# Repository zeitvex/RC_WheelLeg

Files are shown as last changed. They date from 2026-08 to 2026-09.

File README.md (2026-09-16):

关键词：ROBOCON、四足、四轮足、仿生足式、强化学习、RL、Mjlab、Mujoco、Odin1、sim2sim、sim2real。

山东华宇工学院 HYNova 战队轮足机器人项目的开源仓库。

我们是一支从零起步的新队伍。从社团初创到战队成立，从学校历史上首次电赛国一，到 RC 国一，一路走来积累了机械、硬件、控制、仿真和强化学习方面的实践经验。当前仓库已完整开源本项目的机械、硬件、固件、软件、BOM、装配资料、部署文档、训练与比赛版本代码及各类注意事项，希望为起步较晚、正在准备 Robocon 的队伍提供参考。

## 致谢

感谢Robocon青年顾问组对本战队的帮助与支持，感谢[Lain 佬](https://github.com/Lain-Ego0) 的 [LocoWiki](https://github.com/LocoWiki/LocoWiki) 项目对早期方案的参考与启发，衷心感谢哈尔滨工业大学、华南理工大学、东莞理工学院、潍坊科技学院、山东科技大学、太原工业学院、晋中信息学院等院校的战队，在备赛及比赛期间给予我们的鼎力支持与热心帮助。
最后，特别感谢留形科技为 2026 赛季提供的独家赞助与技术支持。

## 战队与项目

* 参赛项目：仿生足式障碍赛
* 最终成绩：全国一等奖，第 7 名，前 5%
* 主要平台：16DOF 串联轮足机器人
* 当前仓库版本：16DOF 串联轮足实机（升级16DOF）

## 版本状态

* 阶段：16DOF 比赛最终版
* 平台：Jetson Orin Nano 8G
* 构型：4 条轮腿，每条腿 3 个腿部关节和 1 个驱动轮
* 执行器：共 16 个执行器（RS02）
* 控制路线：强化学习训练、MuJoCo 仿真、Sim2Sim 验证、Py 与 ROS 2/C++ 双线真机部署
* 当前状态：项目资料已完整开源，包含机械、硬件、固件、软件、BOM、装配、训练、部署和比赛最终版本代码
* 当前版本：`v1.1.1` 最终整理版，补齐完整开源资料说明与代码文档；
* 本仓库为最终完整开源整理版本，后续仅进行必要的问题修正和说明勘误

## 开源内容

本项目沿着“8DOF 基础版本 -> 16DOF 升级版本”的技术路线持续迭代，公开内容也按版本阶段逐步整理和发布。

### 8DOF 基础版本

8DOF 是中期时的串联机器人版本，主要围绕机械结构设计、电机控制、CAN 通信、腿部逆解、PID 调试和基础步态控制展开，为后续的机械升级、仿真训练和真机部署积累了基础经验。完整的 8DOF 机械、硬件和软件资料请查看 [8dof 分支](https://github.com/zeitvex/RC_WheelLeg/tree/8dof)。

### 16DOF 当前版本

当前 `main` 分支主要维护 16DOF 版本的机械、仿真、控制和真机部署资料。

* SolidWorks 2026 版本机械源文件，整机入口为 `02_mechanical/CAD/solidworks/WEEKDOG.SLDASM`。
* 整机、身体、关节、腿部和轮组 STEP 文件，整机入口为 `02_mechanical/STEP/WEEKDOG.STEP`。
* 新一代 `mjlab` 训练任务和本地依赖，位于 `05_software/train/rc_mjlab/`。
* 16DOF 轮足 MuJoCo/MJCF 模型、网格、Sim2Sim 验证工具和早期策略权重。
* 后期 Sim2Sim 工具、导航地图与打点工具、路线数据和抽样 PCD，位于 `05_software/train/rc_mjlab/`。
* IK 轨迹与早期真机控制探索，位于 `05_software/real/ik_real/`。
* 新一代 Python Sim2Real 部署栈，包含策略运行时、电机映射、IMU 接入、站立初始化、安全检查、Web 调试和标定工具。
* Python Sim2Real v2 部署栈，补充电机反馈新鲜度、Odin odom 诊断、命令平滑、Web 运行时诊断和安全监控工具，位于 `05_software/real/sim2real_v2/`。
* ROS 2/C++ Sim2Real 初版工程，将策略热路径迁移到 50 Hz C++ 推理和 200 Hz CAN 电机循环，并加入 ROS 2 消息、命令仲裁、Nav2 和统一启动结构，位于 `05_software/real/sim2real_ros2/`。`sim2real_ros2_v2` 补充导航原型、路线配置、打点工具、遥控串口和 Web/UDP 调试链路，`sim2real_ros2_v3` 整理最终比赛部署、Odin 驱动、TensorRT/ONNX 推理和里程计联调代码，位于 `05_software/real/sim2real_ros2_v2/` 与 `05_software/real/sim2real_ros2_v3/`。
* 新一代 Sim2Real 真机验证视频与预览图。

### 后续整理内容

* 16DOF RL 四轮足相关注意事项以及各类文档。
  
> 当前仓库已完成完整开源整理。请以各目录说明和 Git Tag 对应的版本为准。

## 交流与支持

欢迎正在备赛或对轮足机器人感兴趣的同学加入交流：

* 轮足开源交流群：[点击加入 QQ 群](https://qm.qq.com/q/HkdRYwtAYg)
* 群号：`767195310`

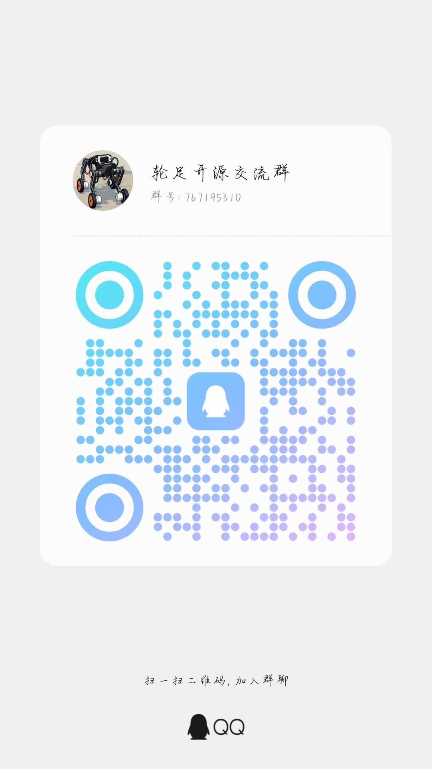
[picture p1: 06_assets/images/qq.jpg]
轮足开源交流群二维码


同时欢迎在群内交流机械设计、硬件搭建、下位机控制、仿真训练、强化学习和真机部署相关问题，也欢迎对本项目提出建议。

## 成员

|成员|方向|主要职责|联系方式|
|-|-|-|-|
|晨小荼(chentu12)|队长 / 算法|构建初创平台；前期负责 8DOF 平台构建与算法，参与硬件和算法方案讨论；后期负责 16DOF 轮足机器人 Odin1 平台建设与硬件实现，负责企业及组委对接，持续推进项目落地。|WX: `r15288746596`<br>QQ: `2898468947`|
|[时维](https://github.com/zeitvex)|技术负责人 / 项管|主导中后期 16DOF 轮足机器人的软件与控制架构，参与机械与硬件方案确定；负责强化学习训练、仿真验证、真机部署、导航集成及项目进度推进和体系建设。|WX: `zeitvex`<br>QQ: `3156045992`|
|[Dichen](https://github.com/Dichen33)|电控 / 算法|负责电控与算法软件架构设计及系统集成。前期完成 8DOF 电机控制、CAN 通信、PID、腿部逆解与步态调试；中后期面向 16DOF 平台负责电机控制、传感器接入、状态估计和导航链路开发，辅助 Odin 接入，并参与仿真验证、强化学习训练及真机部署。|WX: `Dichenccc`<br>QQ: `3357573813`|
|[Sulcunfu](https://github.com/wusi321)|电控 / 机械|参与前期 8DOF 及中后期 8DOF 到 16DOF 的机械升级设计；负责模型总装配、URDF 导出、仿真和算法验证，参与强化学习模型训练优化，配置 Linux 基础部署环境，对接 Odin1 视觉感知、里程计和 IMU 数据，并负责环境建图及导出。|WX: `LcfNotFound`<br>QQ: `3299459360`|
|[王书琪](https://github.com/Beni-537)|机械 / 硬件|负责整机机械结构设计与电气硬件系统搭建；负责 8DOF 开源机械结构的硬件适配，以及 16DOF 架构整体机械结构的建模、优化和 CNC 供应链对接；负责电源管理 PCB 设计与 CAN 总线通信拓扑，为算法和仿真部署提供高刚度、高稳定性的硬件基础。|WX: `DouSfJade`<br>QQ: `3070940094`|

## 实机展示

当前仓库包含 Sim2Real 真机测试记录与比赛初版成果展示，视频与预览图位于 `06_assets/`：

### 最初轮足真机测试记录

<a href="06_assets/videos/early_sim2real.mp4">
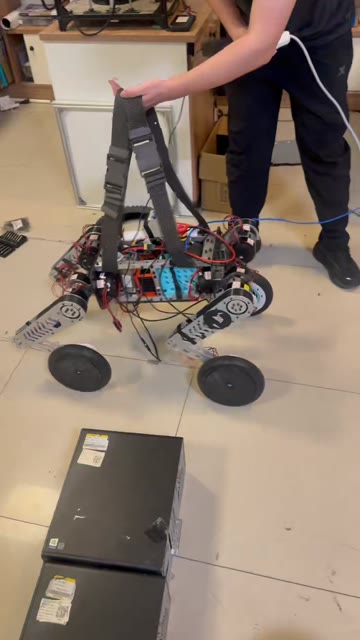
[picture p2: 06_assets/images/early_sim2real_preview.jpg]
第一代 Sim2Real 真机测试记录
  
</a>

第一代 Sim2Real 真机测试记录，时长约 41 秒。点击预览图播放或下载原视频。

### 最终比赛测试记录

<a href="06_assets/videos/sim2real.mp4">
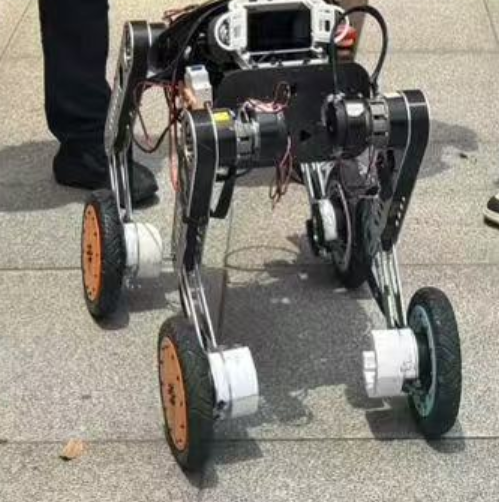
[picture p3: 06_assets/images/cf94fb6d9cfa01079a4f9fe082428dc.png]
比赛初版成果
  
</a>

该视频为完赛效果演示视频，画质为 1280×720 横屏，总时长约 1 分 20 秒，与比赛实际时长接近。点击预览图可播放或下载原视频。

## 目录结构

```text
RC_WheelLeg/
├─ 01_doc/          # 项目技术文档和使用说明
├─ 02_mechanical/   # SolidWorks CAD、STEP 和机械源资料
├─ 03_hardware/     # 自研电路、接线、BOM、传感器与计算平台说明
├─ 04_firmware/     # MCU 或其他嵌入式控制器固件
├─ 05_software/     # 强化学习训练、MuJoCo、Sim2Sim、Sim2Real 和工具
├─ 06_assets/       # 图片、视频和测试结果
├─ .gitignore
└─ README.md
```

## 工程入口

机械资料：

* [`02_mechanical/README.md`](02_mechanical/README.md)
* [`02_mechanical/CAD/solidworks/WEEKDOG.SLDASM`](02_mechanical/CAD/solidworks/WEEKDOG.SLDASM)
* [`02_mechanical/STEP/WEEKDOG.STEP`](02_mechanical/STEP/WEEKDOG.STEP)

软件资料：

* [`05_software/README.md`](05_software/README.md)
* [`05_software/train/README.md`](05_software/train/README.md)
* [`05_software/train/rc_mjlab/README.md`](05_software/train/rc_mjlab/README.md)
* [`05_software/train/rc_mjlab/sim2sim/README.md`](05_software/train/rc_mjlab/sim2sim/README.md)
* [`05_software/train/rc_mjlab/tools/nav_tools/README.md`](05_software/train/rc_mjlab/tools/nav_tools/README.md)
* [`05_software/real/README.md`](05_software/real/README.md)
* [`05_software/real/sim2real/README.md`](05_software/real/sim2real/README.md)
* [`05_software/real/sim2real_v2/README.md`](05_software/real/sim2real_v2/README.md)
* [`05_software/real/sim2real_ros2/README.md`](05_software/real/sim2real_ros2/README.md)
* [`05_software/real/sim2real_ros2_v2/README.md`](05_software/real/sim2real_ros2_v2/README.md)
* [`05_software/real/sim2real_ros2_v3/README.md`](05_software/real/sim2real_ros2_v3/README.md)

媒体资料：

* [`06_assets/README.md`](06_assets/README.md)
* [`06_assets/images/cf94fb6d9cfa01079a4f9fe082428dc.png`](06_assets/images/cf94fb6d9cfa01079a4f9fe082428dc.png)
* [`06_assets/videos/early_sim2real.mp4`](06_assets/videos/early_sim2real.mp4)
* [`06_assets/videos/sim2real.mp4`](06_assets/videos/sim2real.mp4)

## 软件相关

当前 `05_software/` 保存完整软件相关资料：

```text
MJCF + mjlab task
        |
        v
   PPO 训练策略
        |
        +----> MuJoCo 独立模型调试
        |
        +----> Sim2Sim 策略验证
        |
        +----> Python Sim2Real / v2 ----> 电机 / IMU
        |
        +----> ROS 2/C++ Sim2Real / v2 / v3 -> CAN / IMU / 导航与比赛部署

IK real --------------------------------> 电机
```

其中 `rc_mjlab` 是自包含训练与仿真工程，包含 `src/robot` 训练任务、`mjcf` 模型、`mujoco_sim` 独立调试工具、`sim2sim` 验证工具、本地 `mjlab` 依赖和早期策略权重。

`sim2real` 当前部署 `53D -> 16D` 策略模型，控制频率为 50Hz，包含站立初始化、站立平衡、运行时安全检查、零命令保持和首次命令平滑释放逻辑。部署前应先阅读 `05_software/real/sim2real/README.md`、`DEPLOYMENT.md` 和 `ORIN_NANO_DEPLOYMENT.md`。

`sim2real_v2` 对应 Python Sim2Real v2，保留 `53D -> 16D` 策略接口，并增加电机反馈新鲜度、Odin odom 诊断、命令平滑、Web 运行时诊断和安全监控工具。部署前应先阅读 `05_software/real/sim2real_v2/README.md` 和 `DEPLOYMENT.md`。

`sim2real_ros2` 是 ROS 2/C++ Sim2Real 初版；`sim2real_ros2_v2` 补充导航原型、路线配置、打点工具、遥控串口和 Web/UDP 调试链路；`sim2real_ros2_v3` 整理最终比赛部署、Odin 驱动、TensorRT/ONNX 推理和里程计联调。完整入口见 `05_software/real/sim2real_ros2/README.md`、`05_software/real/sim2real_ros2_v2/README.md` 与 `05_software/real/sim2real_ros2_v3/README.md`。

## 安全说明

* 首次运行前必须架空机器人，并确认电机 ID、方向、零位、限位和关节映射。
* 调试时必须确保遥控器、上位机或部署脚本中的急停链路可用。
* 不应在未核对机械限位、仿真模型、策略输出尺度和电机映射的情况下直接上电运行。
* 强化学习策略和 Sim2Real 部署需要先完成离线检查、仿真验证、低速空载测试和小幅动作测试。
* 本项目可能产生较大关节力矩，使用者需要自行承担硬件调试风险。
* 零位设置需在机器人稳定支撑状态下完成，并记录机身、足端、膝关节和轮组的实际姿态，避免后续模型与真机坐标不一致。

## 许可证

本项目采用 [MIT License](LICENSE) 授权。

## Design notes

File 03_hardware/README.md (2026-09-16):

# 硬件

本目录用于保存 16DOF 轮足机器人的自研电路、接线图、BOM、传感器与计算平台说明。

第三方硬件资料不作为自研成果提交。

当前目录仅有范围说明，尚未归档 16DOF 平台的自研原理图、PCB、BOM 或正式接线图，不应将本目录视为已完成的硬件开源包。

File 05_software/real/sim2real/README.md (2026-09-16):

# `sim2real`

本目录是第一代 Python Sim2Real 快照，对应 `v0.3.0`。下文“当前”均指该历史快照，不指仓库 `main` 的最终 ROS 2 v3。

该快照只部署当时的 `53D -> 16D` Rough 模型，不兼容更早的 Crawl、多策略和其他历史观测契约。

## 当前部署模型

- 使用文件：`policies/model_rough.pt`
- 原始说明记录的来源名：`model_2000.pt`；该同名源文件未随本目录归档，仓库只保留重命名后的 `policies/model_rough.pt`

## 当前 actor 输入

- 单帧 `53D`
- 顺序：
  - `base_ang_vel * 0.25`
  - `projected_gravity`
  - `command`
  - `joint_pos_rel`（12）
  - `joint_vel_rel * 0.05`（12）
  - `wheel_vel * 0.05`（4）
  - `last_actions`（16）

不包含：

- `base_lin_vel`
- `height_scan`

## 当前控制参数

- 控制频率：`50Hz`
- 站立保持：`startup/stand_balance.py`
- `hip_abduction` 缩放：`0.125`
- 其他腿关节缩放：`0.25`
- 轮速缩放：`5.0`
- 腿 LPF：`5Hz`
- 轮 LPF：`15Hz`
- 零命令抑制：默认开启，可通过 `config.yaml > policy.enable_zero_cmd_suppression` 关闭
- 零命令保持：默认开启，可通过 `config.yaml > policy.hold_zero_command_pose` 控制
- 首次命令解锁：默认开启，可通过 `config.yaml > policy.require_active_command_to_release` 控制

## 当前站立逻辑

- `startup`：从实测姿态过渡到默认站姿
- `stand_balance`：根据 `IMU roll/pitch + gyro` 动态修正四条腿目标
- `runtime`：只有站立稳定后才进入策略控制

这次改动的重点是：策略不再承担“先把身体撑住”的职责。

另外当前部署逻辑改成：

- 零命令时默认不让策略直接接管腿和轮，保持站立目标
- 命令从零变为非零时，策略输出在 `command_release_s` 内平滑放开

## 启动命令

默认前提：当前目录是 `05_software/real/sim2real/`

纯 `python`：

```bash
python -m pip install -r requirements-orin.txt
python tools/alignment_check.py --policy policies/model_rough.pt --manifest deployment_manifest.yaml
python tools/standalone_check.py
python main.py --dry-run
python main.py
python web/server.py --host 0.0.0.0 --port 8080
```

Windows 本机可使用目标虚拟环境中的 Python；不要依赖个人机器的绝对安装路径：

```bash
python -m pip install -r requirements-orin.txt
python tools\alignment_check.py --policy policies\model_rough.pt --manifest deployment_manifest.yaml
python tools\standalone_check.py
python main.py
python web\server.py --host 0.0.0.0 --port 8080
```

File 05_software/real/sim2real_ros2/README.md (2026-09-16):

# ROS 2/C++ Sim2Real 初版

本目录归档 `real/sim2real_ros2`，对应 `v0.10.0`。这是轮腿机器人 Sim2Real 部署栈从 Python 运行时迁移到 ROS 2 + C++ 的第一版系统工程。

本工程保留当前 `sim2real` 已验证的部署契约，同时将运行时热路径迁移到 C++：

- `53D` 策略观测契约不变
- `16D` 动作契约不变
- `50Hz` 策略循环与训练对齐
- `200Hz` 电机循环为专用 C++ 热路径
- ROS 2 作为导航、TF、诊断和启动管理的系统集成层

## 工作区布局

- `src/sim2real_interfaces`
  硬件桥接与策略运行时共享的 ROS 2 消息定义。
- `src/sim2real_common`
  共享常量、部署契约辅助函数、Mahony 姿态滤波器、站立平衡控制器、安全监控。
- `src/sim2real_hw`
  面向硬件的桥接节点：RobStride CAN 收发、IMU/Odin 数据采集、看门狗、状态发布。
- `src/sim2real_runtime`
  策略运行时节点：`53D→16D` ONNX 推理、命令滤波/仲裁、目标发布。
  同时包含 `odom_relay_node`（里程计中继与 TF 广播）。
- `src/sim2real_nav2`
  ROS 2 Navigation2 (Nav2) 配置包：参数、启动文件、AMCL、costmap、planner/controller。
- `src/sim2real_bringup`
  统一启动文件与运行时参数配置。
- `src/odin_ros_driver`
  仅保留依赖边界说明；原始 `v0.10.0` 快照没有归档 Odin 驱动源码，不能独立提供 IMU、点云和里程计发布。
- `docs`
  架构说明与迁移计划。

## 目标架构

```text
Odin / IMU / Odom  --->  sim2real_hw  --->  sim2real_runtime  --->  sim2real_hw
                              |                  |                    |
                              v                  v                    v
                         RuntimeState       RuntimeTarget          电机 CAN 指令
                              |                  |
                              +-------> 诊断 / 遥测

Nav2 / cmd_vel  ------------------------------>  sim2real_runtime
                   (经 odom_relay_node 提供 odom→base_link TF)
```

## 当前状态

已完成 Phase 0-5 的全部迁移：

1. ✅ 冻结部署契约（deployment_contract.hpp）
2. ✅ ROS 2 包结构搭建
3. ✅ 硬件热路径迁移至 C++（SocketCAN 驱动、200Hz 电机循环）
4. ✅ ONNX 策略运行时迁移至 C++（50Hz 推理循环）
5. ✅ 导航与诊断通过 ROS 2 接入（Nav2 + odom_relay + TF）

## 契约来源

迁移过程中以下文件被视为真值源：

- `../sim2real/deployment_manifest.yaml`
- `../sim2real/interface/motor_mapping.py`
- `../sim2real/interface/real_io.py`
- `../sim2real/policy/policy_runner.py`
- `../sim2real/web/session.py`

## 注意事项

- 开发目标为 Linux + ROS 2 Humble，运行于 Jetson Orin / x86_64。
- Windows 仅作为编辑环境使用。
- 观测顺序、动作缩放、默认站姿、电机映射不得独立修改，
  除非训练与部署同步更新。
- 原始快照中的 `src/odin_ros_driver` 是空目录，本版本仍需要另行提供兼容的 Odin ROS 2 驱动；其源码从后续版本开始随工程归档。
- 自研 ROS 包保留原始 `Proprietary` 清单字段，公开发布前仍需统一许可证和维护者信息。

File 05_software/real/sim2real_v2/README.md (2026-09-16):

# Python Sim2Real v2

本目录归档 Python Sim2Real v2，对应 `v0.9.0`。该阶段从第一代闭环继续演进，保持 `53D -> 16D` 策略契约，重点完善电机反馈判断、IMU/Odin 可观测性、Web 调试和运行时诊断；后续 ROS 2/C++ 版本另行归档。下文“当前”均指该版本快照。

## 当前控制链路

- 策略模型：默认优先使用 `policies/model_rough.onnx`，`.pt` 仅作为导出源和 fallback
- 策略输入：单帧 `53D`
- 策略输出：`16D`
- 控制频率：默认 `50Hz`
- 电机数量：16 个 RS02/RobStride 电机
- 电机映射、方向、零位：以 `interface/motor_mapping.py` 为准，当前视为真机验证过，不在本轮改造中修改
- Web 入口：`python web/server.py --host 0.0.0.0 --port 8080`

策略观测顺序保持不变：

1. `base_ang_vel * 0.25`
2. `projected_gravity`
3. `command`
4. `joint_pos[:12] - default_dof_pos[:12]`
5. `joint_vel[:12] * 0.05`
6. `wheel_vel[12:] * 0.05`
7. `last_actions`

Odin odom 现在只作为诊断和全局状态显示接入，不进入策略观测，避免破坏已训练模型的输入契约。

## 本轮改造内容

- 日志写入改为后台线程，降低 `state.csv` 高频写入对 50Hz 控制循环的阻塞。
- 电机 fresh/stale 判断优先使用驱动层 `update_count`，避免静止电机反馈正常但位置速度不变时被误判为丢电机。
- `wait_feedback_ready()` 同步识别 `update_count`，降低使能后零位静止电机被误判 missing 的概率。
- `IMUClient` 增加 `get_latest_odom()`，读取 Odin odom 的位置、姿态、线速度、角速度、类型和 age。
- `RealIO.read_state()` 增加只读 `odom` 字段，但不改变策略观测。
- 增加 `OdomTracker`，把 Odin raw odom 转成启动点局部坐标 `local x/y/yaw`，并做跳变检测。
- 增加 `LatestTarget` 诊断，记录当前下发目标来源、age、目标变化量，为后续双 loop 解耦铺路。
- Web runtime 状态增加 `loop_profile`、odom、电机 fresh 计数、每电机 update_count。
- Web Diagnostics 面板增加 loop overrun、最慢阶段、电机 fresh 来源、Odin odom 状态。
- 增加 `command_filter`，对 Web/遥控命令统一做限加速度平滑，降低起停冲击；Web 同时显示 raw cmd 和 filtered cmd。
- 策略推理入口改为 ONNXRuntime 优先，默认查找 `policies/model_rough.onnx`；不存在时兼容回退到 `policies/model_rough.pt`。
- ONNXRuntime 使用 CPU 单线程顺序执行，减少推理线程池和 motor/status/logger 线程抢占。

## 重点诊断字段

Web 中重点看这些项：

- `loop_dt`：控制循环总耗时，50Hz 下目标约 `20ms`。
- `Loop Overruns`：runtime 超时累计次数和最大超时。
- `Loop Profile`：显示本轮最慢阶段，例如 `read_state_ms`、`policy_ms`、`send_actions_ms`。
- `Latest Target`：显示目标来源、age 和本次目标最大变化量；age 异常增大说明目标更新链路卡住。
- `Obs / Action`：显示观测绝对值最大值、raw action 最大值和 scaled action 最大值，用来发现输入爆炸或动作饱和。
- `Motor Fresh`：格式为 `fresh/16 (cnt x, val y)`；`cnt` 表示通过 `update_count` 确认的新反馈数量。
- `Odin Odom`：显示 odom 类型、age、local x/y/yaw；没有 odom 时不影响控制。
- `cmd/raw cmd`：`cmd` 是进入策略的滤波后命令，`raw cmd` 是 Web/遥控原始命令。
- 电机列表状态点：绿色代表 stale count 为 0，黄色代表短时未刷新，红色代表连续 stale。

## 当前仍需实机重点确认

- 如果继续出现 `LOOP_OVERRUN`，先看 Web 的 `Loop Profile`，不要直接调低控制频率。
- 如果 `read_state_ms` 慢，重点排查 SocketCAN/CAN 队列、Odin bridge 或电机反馈处理。
- 如果 `policy_ms` 慢，重点排查 ONNXRuntime 推理耗时、CPU 占用和是否有后台进程抢占。
- 如果 `send_actions_ms` 慢，重点排查 CAN 发送阻塞或 USB-CAN 适配器。
- 如果 `Obs / Action` 中 obs 接近 `100` 或 raw action 接近 `10`，说明策略输入/输出可能在饱和边界，需要优先检查观测缩放、IMU、关节速度和命令。
- 如果 `Motor Fresh` 不是 16/16，但 `update_counts` 在增长，需要检查 Web stale 阈值而不是电机丢失。
- 如果 odom age 长时间不更新，只影响全局坐标/诊断，不应影响当前策略控制。

## 启动命令

在 Orin / Linux 真机上：

```bash
python -m pip install -r requirements-orin.txt
python tools/export_onnx.py --pt policies/model_rough.pt --onnx policies/model_rough.onnx
python tools/alignment_check.py --policy policies/model_rough.onnx --manifest deployment_manifest.yaml
python tools/standalone_check.py
python web/server.py --host 0.0.0.0 --port 8080
```

Web 流程：

1. Connect
2. Enable Motors
3. Startup
4. Start Runtime
5. 策略 release 后，如需要，点击遥控接管
6. 实时观察 Diagnostics、Motors、Plots

## 安全边界

当前保留原有保护链路：

- Web 急停
- 遥控软急停
- runtime guard
- safety monitor
- NaN/Inf 检查
- 电机 stale holdover
- damping brake

这轮没有放宽安全边界，也没有调整电机限位、零位、方向、默认增益和策略动作缩放。

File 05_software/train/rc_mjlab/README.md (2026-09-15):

# rc_mjlab

基于 [mjlab](https://github.com/mujocolab/mjlab) 的 16DOF 串联轮足机器人强化学习、MuJoCo 验证与策略部署工程。

## 版本定位

当前目录是多个里程碑累积后的工作树，不应整体写成“对应 `v0.8.1`”：

| Tag | 本目录中的主要变化 |
| --- | --- |
| `v0.4.0` | 第一份新 MJCF 与新 mjlab 训练基线（`uni_mjlab(1)`） |
| `v0.5.0` | 随机化增强训练版本（`uni_mjlab_new`） |
| `v0.6.0` | `best` 比赛训练架构：分轴速度奖励、自适应指令课程和障碍释放课程 |
| `v0.7.0` | 补充后期 `mujoco_sim` 姿态、IK、动力学和 MPC 工具 |
| `v0.8.0` | 补充后期 Sim2Sim、路线检查和比赛 Rough 策略 `model_6800.onnx` |
| `v0.8.1` | 补充导航打点、路线迭代与抽样 PCD 工具 |

后续 ROS 2 真机版本没有把本目录重新定义为新的训练版本。要查看某个阶段的真实代码，请切换对应 Tag；当前训练主体以 `v0.6.0` 的 `best` 架构为基础，工具链累计到 `v0.8.1`。

## 目录说明

```text
rc_mjlab/
├─ src/robot/           # Robot-Flat/Rough/Crawl 任务、PPO 配置和本地 RSL-RL/HIM 代码
├─ mjcf/                # 机器人、场景与网格资源
├─ mjlab/               # 固定基准并带本地补丁的 mjlab 源码
├─ mujoco_sim/          # 姿态、IK、动力学、MPC 与 GUI 工具
├─ sim2sim/             # ONNX/PT 回放、比赛场景、IK 与路线检查
├─ tools/nav_tools/     # PCD、地图、航点和路线编辑工具
├─ model_rough.pt       # 早期 Rough 参考 checkpoint
├─ model_6800.onnx      # 比赛最终部署使用的 Rough 策略
├─ pyproject.toml       # Python 包和依赖声明
├─ uv.lock              # 历史环境的精确锁文件
└─ DEPENDENCIES.md      # 上游基准、本地补丁和可选依赖说明
```

`model_6800.onnx` 是最终部署工件，不等于训练代码版本号。训练过程中存在基模、继续训练和 checkpoint 筛选，仅凭该 ONNX 不能恢复完整训练日志。

## 已注册任务

| Task ID | 用途 | 默认训练时长 |
| --- | --- | --- |
| `Robot-Flat-v0` | 平地基础运动 | 20 s/episode |
| `Robot-Rough-v0` | 粗糙地形、台阶、随机网格、高墙和坡面 | 20 s/episode |
| `Robot-Crawl-v0` | 低杆、低姿态和匍匐任务 | 30 s/episode |

任务入口由 [`src/robot/__init__.py`](src/robot/__init__.py) 注册；环境真值见 [`src/robot/config/env_cfgs.py`](src/robot/config/env_cfgs.py)，PPO 真值见 [`src/robot/config/rl_cfg.py`](src/robot/config/rl_cfg.py)。

## 当前控制与模型参数

以下参数来自当前工作树源码，不代表所有历史 Tag：

| 项目 | 当前值 |
| --- | --- |
| MuJoCo 物理步长 | `0.005 s`（200 Hz） |
| 控制降采样 | `decimation = 4` |
| 策略周期 | `0.020 s`（50 Hz） |
| 默认并行环境 | 2048 |
| 腿部执行器 | 位置控制，`Kp=50.0`、`Kd=1.5`、力矩上限 `17 Nm` |
| 轮部执行器 | 速度控制，`Kd=1.0`、力矩上限 `17 Nm` |
| 关节速度参考常量 | `13 rad/s`；当前 Builtin actuator 构造未显式传入该常量 |
| 默认站姿 | hip pitch `0.550`、knee `-1.125`、机身高度 `0.42 m` |
| 外展关节动作缩放 | `0.125 rad` |
| 其余腿关节动作缩放 | `0.25 rad` |
| 轮速动作缩放 | `5.0 rad/s` |
| 动作延迟 | 每个环境随机 `0～2` 个控制步 |
| 低通截止频率 | 腿 `5 Hz`、轮 `15 Hz` |

README 原先写的 `0.002 s × decimation 10`、4096 环境、`Kp=40/Kd=1` 和轮部 `Kd=0.5` 均不对应当前代码，已删除。

## 观测与动作契约

Actor 单步观测为 53 维：

| 观测项 | 维度 |
| --- | ---: |
| 基座角速度 | 3 |
| 投影重力 | 3 |
| 速度/航向指令 | 3 |
| 12 个腿关节相对位置 | 12 |
| 12 个腿关节速度 | 12 |
| 4 个轮关节速度 | 4 |
| 上一步 16 维动作 | 16 |

动作共 16 维：12 个腿关节位置目标和 4 个轮关节速度目标。Critic 在 Actor 观测之外增加基座线速度、轮地接触和高度扫描等特权信息。

## Rough 当前配置摘要

`Robot-Rough-v0` 当前混合八类地形：

| 地形 | 比例 | 当前范围摘要 |
| --- | ---: | --- |
| 平地 | 15% | 8 m × 8 m |
| 正向台阶 | 5% | 阶高 `0～0.20 m` |
| 反向台阶 | 35% | 阶高 `0～0.20 m` |
| 随机网格 | 27% | 高度 `0～0.20 m` |
| 随机粗糙面 | 1% | 起伏 `0～0.06 m` |
| Perlin 噪声 | 1% | 起伏 `0～0.06 m` |
| 自定义高墙 | 15% | 高度 `0.10～0.35 m` |
| 金字塔坡面 | 1% | 坡度 `0.052～0.325` |

课程学习从平地、粗糙面、Perlin、坡面和正向台阶开始，随后按训练步数释放随机网格、反向台阶和高墙。同时对 X、Y、Yaw 三个指令轴分别做自适应范围调整。

当前 Rough 奖励使用分轴 `vx/vy/yaw` 跟踪，并启用每步总奖励不低于 0 的截断，而不是旧 README 中的 `track_lin_vel=4.5`、`track_ang_vel=2.0`。它还包含动作变化率、扭矩/功率、腿轮加速度、关节限位、镜像姿态、静止姿态、接触力和非期望碰撞等约束；精确权重以 `rough_env_cfg()` 为准。

## 当前域随机化边界

基础配置实际启用的主要随机项包括：

- 基座质心三轴偏移：各 `[-0.05, 0.05] m`；
- 碰撞几何摩擦：`[0.3, 1.0]`；
- 执行器刚度、阻尼缩放：各 `[0.9, 1.1]`，log-uniform；
- 基座附加质量：`[-1.0, 3.0] kg`；
- Rough 间歇推扰：每 `5～10 s` 设置一次 X/Y `[-0.5, 0.5] m/s` 速度扰动；
- 关节动作延迟：`0～2` 个策略步。

旧 README 中列出的 encoder bias、持续外力、关节摩擦和力矩上限随机化并非当前 Rough 配置的完整真实状态，因此不再作为“当前已启用项”陈述。历史随机化差异见 [`../../../01_doc/training_evolution.md`](../../../01_doc/training_evolution.md)。

## 环境安装与基本命令

在本目录执行：

```bash
uv sync

uv run train Robot-Flat-v0
uv run train Robot-Rough-v0
uv run train Robot-Crawl-v0

uv run play Robot-Rough-v0
```

GPU、CUDA、MuJoCo development wheel 和驱动要求见 [`DEPENDENCIES.md`](DEPENDENCIES.md)。恢复训练时需要明确 checkpoint/run 来源，不建议仅凭 README 猜测跨实验热启动参数。

## Sim2Sim 与导航工具

```bash
uv run --with-requirements sim2sim/requirements.txt python sim2sim/nav_sim2sim.py

uv run --with-requirements tools/nav_tools/requirements.txt python tools/nav_tools/nav_map_viewer.py
```

- 后期 Sim2Sim 入口和策略边界：[`sim2sim/README.md`](sim2sim/README.md)
- 导航打点与路线数据：[`tools/nav_tools/README.md`](tools/nav_tools/README.md)
- 训练版本演进：[`../../../01_doc/training_evolution.md`](../../../01_doc/training_evolution.md)
- 全项目版本历史：[`../../../01_doc/version_history.md`](../../../01_doc/version_history.md)

## 复现边界

- `uv.lock` 保存依赖解析结果，但仍需要匹配的 NVIDIA 驱动和 CUDA 环境。
- TensorRT engine 属于真机部署环境，本目录以训练代码、PT/ONNX 和仿真验证为主。
- 比赛最终真机工程位于 [`../../real/sim2real_ros2_v3`](../../real/sim2real_ros2_v3)。
- 参数若与本文冲突，以当前 Tag 中的配置源码为准；不同 Tag 之间不要直接混用奖励权重、站姿和模型。

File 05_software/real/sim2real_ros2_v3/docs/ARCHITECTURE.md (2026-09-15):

# sim2real_ros2_v3 架构说明

## 设计目标

- 保留已验证的 RL 部署契约不变
- 将低延迟循环从 Python 迁移至 C++
- 暴露标准 ROS 2 接口用于导航和系统集成
- 保持安全边界独立于策略正确性

## 各包职责

### `sim2real_interfaces`（接口消息）

定义最小化的运行时消息：

- `RuntimeState`
  硬件桥接发布的归一化运行时状态快照
- `RuntimeTarget`
  策略运行时发送至硬件桥接的最新策略目标

### `sim2real_common`（共享常量）

存储编译期常量和部署契约辅助：

- 观测维度和字段布局
- 动作维度和轮子索引
- 关节顺序和默认站姿
- 动作缩放因子和默认循环频率
- Mahony 姿态滤波器
- 站立平衡控制器
- 安全监控器（SafetyMonitor / RuntimeGuard）

### `sim2real_hw`（硬件桥接）

拥有硬件侧执行循环和安全边界：

- RobStride CAN 收发
- IMU 与 Odin 状态采集
- 电机丢帧检测与保活逻辑（holdover）
- 看门狗与阻尼刹车
- 发布 `RuntimeState`
- 订阅 `RuntimeTarget`
- 订阅 `/odom` 里程计数据

目标热路径：

- 以 `200Hz` 频率读取状态
- 应用最新安全目标
- 超时或安全违规时立即停机

### `sim2real_runtime`（策略运行时）

拥有策略侧执行：

- 订阅 `RuntimeState`
- 按当前部署契约精确构建 `53D` 观测
- 以 `50Hz` 运行 ONNXRuntime 推理
- 对 raw_action 做 `[-10, 10]` 安全裁剪
- 发布 `RuntimeTarget`
- 仲裁命令来源：estop > safety_hold > startup > navigation > web

同时包含：
- `odom_relay_node`：将 `/odin1/odometry` 中继为 `/odom`，帧名 `odin1_base_link` → `base_link`，并广播 TF

### `sim2real_nav2`（导航配置）

拥有：

- Nav2 参数文件（planner、controller、costmap、AMCL、behavior）
- Nav2 启动文件（含 AMCL、costmap 生命周期节点、pointcloud_to_laserscan）

### `sim2real_bringup`（启动管理）

拥有：

- 参数文件
- 启动组合
- 运行时模式选择
- 集成 odin_ros_driver、sim2real_nav2 的条件启动

## 迁移规则

1. 优化之前先冻结当前契约
2. 先迁移传输和循环结构，再调整控制算法
3. C++ 运行时未达到影子模式一致性前，保留 Python 运行时可用
4. 按段测量延迟：
   - 观测延迟
   - 策略推理延迟
   - 目标传输延迟
   - 执行器响应延迟

## 首个里程碑

首个里程碑不是"机器人在 ROS 2 下行走"，而是：

1. `sim2real_hw` 发布稳定的 `RuntimeState`
2. `sim2real_runtime` 从该状态构建正确的 `53D` 观测
3. `sim2real_runtime` 以 `50Hz` 发布 `RuntimeTarget`
4. `sim2real_hw` 消费最新目标并执行超时刹车
5. `cmd_vel` 可通过 ROS 2 注入而不改变策略契约

> ✅ 以上里程碑已全部完成。

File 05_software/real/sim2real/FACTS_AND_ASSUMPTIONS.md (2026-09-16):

# `FACTS_AND_ASSUMPTIONS`

> 版本范围：第一代 Python Sim2Real（`v0.3.0`）。事实项只适用于该快照。

## 已确认

- 当前部署模型：`policies/model_rough.pt`
- 原始说明记录的源模型名：`model_2000.pt`；同名文件未随本目录归档
- actor 输入：`53D`
- actor 输出：`16D`
- 当前 actor 不吃 `base_lin_vel`
- 当前 actor 不吃 `height_scan`

## 当前观测顺序

1. `base_ang_vel * 0.25`
2. `projected_gravity`
3. `command`
4. `joint_pos_rel`（12）
5. `joint_vel_rel * 0.05`（12）
6. `wheel_vel * 0.05`（4）
7. `last_actions`（16）

## 当前控制定义

- 控制频率：`50Hz`
- 腿缩放：`0.125 / 0.25`
- 轮缩放：`5.0`
- 腿 LPF：`5Hz`
- 轮 LPF：`15Hz`

## 当前仍依赖现场一致的部分

- IMU 安装方向与上一版校正一致
- 当前 MJCF / 电机参数对应这次重新训练后的模型
- 电机零位、方向、接线已按当前硬件修正

## 本次实现边界

不再支持：

- `crawl` 模型
- 多策略切换
- `318D` 历史输入
- 旧版 `startup.start_pose`

## 本次排查结论

代码应只围绕当前 rough 模型运行。  
如果后续模型结构再改，必须重新核对观测、动作缩放、控制频率和部署文档。

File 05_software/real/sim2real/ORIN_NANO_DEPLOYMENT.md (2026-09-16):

# `Orin Nano` 部署说明

> 版本范围：第一代 Python Sim2Real（`v0.3.0`）。本文不是最终 ROS 2 v3 部署指南。

## 是否必须转 ONNX

不必须。

当前优先级仍然是：

1. 先保证观测、动作、站立控制对齐
2. 再测 `50Hz` 实际环路稳定性
3. 最后才决定是否转 `ONNX/TensorRT`

## 当前代码重点

- `stand_balance` 已加入 `main.py` 和 `web/session.py`
- 启动后先站稳，再允许策略接管
- `PolicyRunner.step()` 仍保留零命令抑制开关，默认开启

## Orin 上先测什么

- 机器人能否在不启动策略时，仅靠 `startup + stand_balance` 稳定站住
- `loop_dt_ms`
- `imu_age_ms`
- 电机 stale
- policy forward 耗时

## 纯 Python 部署命令

默认前提：当前目录是 `05_software/real/sim2real/`

```bash
python3 -m pip install -r requirements-orin.txt
python3 tools/alignment_check.py --policy policies/model_rough.pt --manifest deployment_manifest.yaml
python3 tools/standalone_check.py
python3 main.py --dry-run
python3 main.py
python3 web/server.py --host 0.0.0.0 --port 8080
```

## 首轮实机建议

1. 先不启动策略
2. 只验证 `startup -> stand_balance`
3. 站稳后再启动策略
4. 只给很小的 `vx / vy / yaw`

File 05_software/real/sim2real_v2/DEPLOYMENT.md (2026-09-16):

# 真机部署与验证指南

本文档面向仓库中的 `05_software/real/sim2real_v2`（`v0.9.0`），用于减少上机排错时间。默认不修改该快照中已验证的电机映射、方向、零位和策略观测。

## 1. 前期环境

推荐在 Orin / Linux 上运行：

```bash
cd 05_software/real/sim2real_v2
python -m pip install -r requirements-orin.txt
```

确认设备：

```bash
ip link show can0
ip link show can1
ls -l /dev/ttyACM0
```

确认 `config.yaml`：

- `can1_port` 和 `can2_port` 对应实际 SocketCAN 设备。
- `control_freq` 默认保持 `50`。
- `remote.port` 默认 `/dev/ttyACM0`。
- `policy.action_scale` 必须是 16 维。
- 默认策略文件优先使用 `policies/model_rough.onnx`；如果只有 `.pt`，先用 `tools/export_onnx.py` 导出。
- `controller.kp_leg/kd_leg/kd_wheel` 不要在未记录实验的情况下大改。

## 2. 无硬件/低风险检查

先做文件和模型契约检查：

```bash
python tools/export_onnx.py --pt policies/model_rough.pt --onnx policies/model_rough.onnx
python tools/alignment_check.py --policy policies/model_rough.onnx --manifest deployment_manifest.yaml
python tools/standalone_check.py
python -m py_compile tools/logger.py interface/motor_driver.py interface/imu_client.py interface/real_io.py web/session.py
```

`alignment_check.py` 会同时检查：

- 策略 obs/action 维度。
- action scale。
- default pose。
- joint order。
- wheel indices。
- `config.yaml` 与 `deployment_manifest.yaml` 的控制频率和 command filter 是否一致。
- ONNX 策略的 obs/action 维度是否仍为 `53D/16D`。

如果有 Node 环境，可检查前端语法：

```bash
node --check web/static/app.js
```

## 3. 上电前检查

上电前确认：

- 机器人架空或有可靠支撑。
- 16 个电机 CAN 线和电源线固定。
- Odin1 连接稳定，启动时机器人尽量静止，利于重力对齐。
- Web 急停可见，遥控软急停通道可用。
- CAN 设备名和遥控串口名与 `config.yaml` 一致。

## 4. Web 启动

```bash
python web/server.py --host 0.0.0.0 --port 8080
```

浏览器打开：

```text
http://<orin-ip>:8080
```

推荐先只看状态，不急着释放遥控。

## 5. 标准上机流程

1. 点击 `Connect`，确认 IMU/Odin 和 CAN 初始化正常。
2. 点击 `Enable Motors`，确认 16 个电机都有反馈。
3. 点击 `Startup`，从当前实测姿态过渡到站立。
4. 进入 `STAND_HOLD` 后观察 IMU age、Motor Fresh、Loop Profile。
5. 点击 `Start Runtime`，进入 50Hz 策略循环。
6. 策略 release 后再点击遥控接管。
7. 小幅给命令，先测试前后、转向，再测试组合动作。

## 6. 本轮新增诊断如何看

`Loop Profile`：

- `read_state_ms` 高：优先查电机接收、CAN 队列、Odin 获取是否阻塞。
- `policy_ms` 高：优先查策略推理和 CPU 负载。
- `send_actions_ms` 高：优先查 CAN 发送和 USB-CAN 适配器。
- `log_ms` 高：说明日志队列或磁盘仍可能有压力。

`Motor Fresh`：

- 理想状态是 `16/16 (cnt 16, val 0)` 或接近。
- `cnt` 高说明 `update_count` 正常增长，这是最可靠的电机反馈证据。
- 如果机器人静止时 `val` 为 0 是正常现象，不应据此判断丢电机。

`Odin Odom`：

- 显示 `STANDARD/HIGHFREQ/TF`、age、local x/y/yaw。
- 当前只用于诊断和全局坐标显示，不参与策略输入。
- odom 不可用时，当前 locomotion 仍应可以运行。
- 如果显示 `JUMP`，说明 odom 局部位置或 yaw 出现突变，先不要把它用于闭环导航。

`Latest Target`：

- 显示当前电机目标来源，例如 `runtime_policy`、`runtime_zero_hold`、`runtime_release_hold`。
- `age` 应随 runtime 正常刷新；如果明显超过控制周期很多，说明目标更新链路卡住。
- `d` 是相邻目标最大变化量，可用于观察停车/起步是否有目标突变。

`Obs / Action`：

- `obs` 接近 `100` 时，说明观测可能接近 clip 边界。
- `raw` 接近 `10` 时，说明策略输出可能接近 raw action 裁剪边界。
- `scaled` 长期很大时，检查 action scale、目标限幅和 safety clip。

`cmd/raw cmd`：

- `raw cmd` 是 Web/遥控原始输入。
- `cmd` 是经过 `command_filter` 限加速度后的策略命令。
- 如果机器人响应慢，先看两者差值是否由命令滤波造成。

## 7. 如果出现前后晃动

先不要直接改控制频率。按顺序排查：

1. 看 `Loop Overruns` 是否增长。
2. 看 `Loop Profile` 最慢阶段。
3. 看 `imu_age` 是否超过 30-60ms。
4. 看 `Motor Fresh` 是否掉到 16 以下。
5. 看停止时 `cmd` 是否真的回到 0。
6. 看 `runtime_released`、`release_alpha` 和 `track_err` 是否异常。

只有确认 50Hz 长期跑不稳时，才把 `control_freq: 40` 作为诊断实验，而不是默认方案。训练/部署频率不一致可能引入新的 sim2real gap。

## 8. 日志

每次运行会生成：

- `state.csv`：高频状态流，后台线程写入。
- `events.jsonl`：事件流，关键事件会即时 flush。

重点搜索：

```bash
grep LOOP_OVERRUN web/logs/*/events.jsonl
grep SAFETY web/logs/*/events.jsonl
grep GUARD web/logs/*/events.jsonl
```

## 9. 当前不建议改动的内容

- 16 个电机映射、方向、零位。
- 策略 53D 观测顺序和缩放。
- 16D 动作顺序和 action scale。
- 默认 `50Hz` 控制频率。
- 已经真机跑通过的遥控方向配置。

这些内容只有在有新日志和明确现象时再改，避免把已验证链路打散。

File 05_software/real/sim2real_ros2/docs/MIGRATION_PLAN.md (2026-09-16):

# 迁移计划

> 版本范围：ROS 2/C++ 初版（`v0.10.0`）。这是历史迁移记录，不是最终比赛版验收报告；本快照未归档 Odin 驱动源码。

## Phase 1: 硬件核心迁移 ✅ 已完成

将当前高频热路径从 Python 迁出。

吸收的源文件：

- `sim2real/interface/motor_driver.py`
- `sim2real/interface/motor_mapping.py`
- `sim2real/interface/imu_client.py`
- `sim2real/safety/runtime_guard.py`
- `sim2real/web/session.py`

交付物：

- C++ SocketCAN 电机总线封装
- C++ 状态缓存
- target 超时保活（timeout hold）
- 阻尼刹车 / 急停通路
- 发布 `RuntimeState`

## Phase 2: 策略运行时迁移 ✅ 已完成

吸收的源文件：

- `sim2real/policy/policy_runner.py`
- `sim2real/interface/real_io.py`
- `sim2real/web/session.py`

交付物：

- 精确的 `53D` 观测构造器
- ONNXRuntime C++ 推理封装
- `50Hz` 策略定时器
- 命令平滑与来源仲裁
- raw_action `[-10, 10]` 安全裁剪
- 发布 `RuntimeTarget`

## Phase 3: ROS 2 系统集成 ✅ 已完成

参考过的外部项目包括 Odin ROS 驱动、EDULITE A3 ROS 工程和 RL-SAR；这些外部参考目录不属于本仓库公开内容。

交付物：

- `cmd_vel` / `cmd_vel_stamped` 输入（支持 Twist 和 TwistStamped）
- `odom_relay_node`：里程计中继 + TF 广播（odom → base_link）
- 诊断话题
- rosbag/foxglove 可观测性

## Phase 4: 导航集成 ✅ 已完成

目标：

- 导航通过 ROS 2 发送身体速度指令
- RL 运行时保持为 locomotion 控制器
- 看门狗和安全边界始终在导航之下

规则：

- 导航绝不直接写电机指令
- 策略契约在重新训练前保持不变
- 任何新增历史项或里程计项必须版本化

## 当前状态

所有 4 个 Phase 已全部完成。以下为已实现的关键组件：

| 组件 | 节点 | 说明 |
|---|---|---|
| 硬件桥接 | `sim2real_hw_node` | 200Hz CAN 收发 + IMU + Mahony + 安全 |
| 策略运行时 | `sim2real_runtime_node` | 50Hz ONNX 推理 + 53D 观测 + raw_action clip |
| 里程计中继 | `odom_relay_node` | /odin1/odometry → /odom + odom→base_link TF |
| 导航栈 | Nav2 全套节点 | AMCL + costmap + DWB + Navfn + BT + lifecycle |
| 传感器驱动 | 外部 Odin 驱动 | 本快照未归档源码，不能视为自包含组件 |
| 点云转换 | `pointcloud_to_laserscan` | 外部 ROS 包；/odin1/cloud_slam → /scan（供 AMCL 使用） |

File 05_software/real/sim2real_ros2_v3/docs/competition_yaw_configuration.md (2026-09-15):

# Pure Pursuit Yaw检查优化 - 最终配置

## 🎯 核心问题

**现象**: 机器人没转到位就开始前进 → 斜着撞杆子

**根本原因**: Pure Pursuit的yaw检查不够严格

---

## ✅ 已修改的参数

### runtime.yaml

```yaml
# 关键修改1: Script模式yaw门限
nav_slalom_script_yaw_gate_deg: 8.0  # 从12度 → 8度

# 关键修改2: 全局yaw容差
nav_goal_yaw_tolerance_deg: 8.0      # 从12度 → 8度
```

**作用**:
- yaw偏差 > 8度时：只转向，不前进
- yaw偏差 ≤ 8度时：才允许前进

---

## 📊 完整配置总结

### 1. 禁用干扰的规划器
```yaml
nav_local_planner_enabled: false
nav_astar_enabled: false
```

### 2. 速度和精度
```yaml
nav_slalom_max_vx: 0.50
nav_slalom_lookahead: 0.15
nav_slalom_tolerance: 0.05
```

### 3. Yaw控制（新增）
```yaml
nav_goal_yaw_tolerance_deg: 8.0
nav_slalom_script_yaw_gate_deg: 8.0
```

---

## 🔍 工作原理

### Pure Pursuit算法流程
```
1. 看前方lookahead距离的目标点
2. 计算到目标的方向和距离
3. 检查yaw偏差
   - 如果 yaw偏差 > yaw_gate (8度):
       只发wz转向，vx=0
   - 如果 yaw偏差 ≤ yaw_gate (8度):
       发vx前进 + wz微调
4. 到达目标点，推进下一个
```

### 之前的问题
```
yaw_gate = 12度（太宽松）
↓
yaw偏差11度时就开始前进
↓
还没对准就冲出去
↓
斜着撞杆子
```

### 修改后
```
yaw_gate = 8度（更严格）
↓
yaw偏差必须≤8度才前进
↓
基本对准后才移动
↓
不会斜着撞
```

---

## 📁 使用的文件

**路线**: `points_nav1007_optimized.json`
- 总航点: 47
- 绕杆航点: 21
- 参数: speed=0.50, lookahead=0.15, tolerance=0.05

**地形**: `tools/nav_tools/xml/A.xml`

**配置**: `runtime.yaml` (已修改)

---

## 🚀 下一步

### 实机测试
```bash
# 1. 重启系统加载新配置
ros2 launch sim2real_bringup sim2real_system.launch.py

# 2. 验证参数
ros2 param get /sim2real_simple_nav_node nav_slalom_script_yaw_gate_deg
# 应该显示: 8.0

ros2 param get /sim2real_simple_nav_node nav_goal_yaw_tolerance_deg
# 应该显示: 8.0

# 3. 加载路线
# 当前归档默认使用: sim2real_ros2_v3/map/routes/1hao_reall.json

# 4. 监控
ros2 topic echo /cmd_vel_nav
# 观察: 转向时vx应该接近0，对准后才有vx速度
```

---

## 💡 预期效果

**修改前**:
- 机器人边转边进
- yaw偏差大时仍有前进速度
- 导致斜着撞杆子

**修改后**:
- 转向时几乎不前进（vx≈0）
- 对准后才快速前进（vx=0.5）
- 动作分离：先转向，后前进

---

## ⚠️ 如果还有问题

### 场景A: 还是斜着撞
可能需要进一步收紧:
```yaml
nav_slalom_script_yaw_gate_deg: 5.0  # 改为5度
```

### 场景B: 太慢，一直在转
说明yaw_gate太严格:
```yaml
nav_slalom_script_yaw_gate_deg: 10.0  # 放宽到10度
```

### 场景C: 卡顿
检查是否在等待yaw对准:
```bash
ros2 topic echo /simple_nav/status
# 看是否一直在"aligning"状态
```

---

**配置已优化完成，ready for testing!** 🎯

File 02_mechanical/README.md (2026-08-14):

# 16DOF 轮足机器人 · Bonjour

> Bonjour（皮带绷住...）૮₍ •ᴗ•ₐა

大家好！本次为大家带来的是 **Bonjour** 上场参赛的最终版本。

我们在 8DOF 的基础上进行了以下升级：

## 1. 机身主板与髋关节固定优化

身体前后两片主板新增了两个髋关节电机的固定位置，并将材料由铝合金更换为碳纤维，以减轻重量、提升美观度。

## 2. 传动连接结构调整

移除了 8DOF 中的"电机连接2"，新增了转接件，将大腿电机与髋关节电机直接相连。

## 3. 小腿板轮足适配

将小腿板修改为适配轮足版本，并提供了一版小腿板模型，其孔位可兼容轮子与宇树足端的拆卸切换。不过这个方案实际并不太适合我们队，所以最终被否掉了，如果大家想要的话可以找我们提供。

---

## 致谢

在此，我们想特别感谢以下开源项目与团队：

1. **Lain 佬与福建理工大学**：再次由衷感谢开源的 8DOF 串联机械方案。正是这份宝贵的资料，让我们这些起步较晚的队伍有了清晰的学习路径和设计基础，也让我们感受到了无私分享的力量。

2. **武汉工程大学【RM2023-平衡步兵充气轮开源】**：衷心感谢其开源方案，为我们在轮子设计方面提供了非常重要的参考。我们在此基础上将外侧轮毂修改为适配 RS02 与机器犬轮足设计的版本。

正是因为你们的开放与包容，我们这些基础薄弱、起步较晚的队伍才有机会站在前人的肩膀上学习和进步。这些开源资料对我们来说不仅是技术参考，更是一份珍贵的学习指引！
---

## 注意事项

### 1. 传动方案建议

建议将"齿轮+皮带"的传动方式改为**连杆传动**，作为大腿与小腿之间的传动方案。在解决后腿电机发热的同时还可以增强设备在转弯时的刚性。

我们在 26 赛季使用皮带时遇到的问题是：齿轮会将皮带拉得过紧，给电机输出轴施加极大的径向载荷；再加上 Bonjour 整体重心偏后，导致后小腿电机发热严重。同时，皮带还可能面临老化、被齿轮磨平、跳齿、以及因过于紧绷而断裂等风险。

> 注：因为 Bonjour 的皮带在实际调试中并未出现皮带绷不住断裂的情况，所以给它起名 Bonjour（绷住了...）૮₍ •ᴗ•ₐა

### 2. 轮子材质建议

轮子部分我们全部使用 **PETG** 材料。但强烈强烈建议外侧轮毂使用**玻纤板或碳纤板**代替，否则外侧轮毂与电机输出轴相连的位置会直接断裂（实测）。

### 3. 后续开源计划

Odin1 保护壳、Nano 固定盒等文件后续会陆续开源。

## 说明（PS）

由于本人来自信息工程学院，此前未系统学习过机械专业知识，也未系统学习过 SolidWorks 的使用方法与绘图规范，因此开源的 SW 文件中可能会有报错或警告（O_o），还请大家谅解。如果文件中有任何不足之处，也欢迎大家批评指正，我们希望能和大家一起交流、共同进步。

机械组联系方式：

王书琪（JadeCrane）  WX：DouSfJade QQ:3070940094

Sulcunfu（wusi321） WX：LcfNotFound QQ：3299459360

---

欢迎各位交流指正，也感谢每一位愿意提出宝贵建议的朋友！

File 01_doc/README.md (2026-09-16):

# 项目文档

本目录用于保存 16DOF 轮足项目自身的技术文档和使用说明。

当前文档结构：

```text
01_doc/
├─ architecture/
│  └─ early_software_stack.md  # 第一代训练—仿真—真机闭环
├─ training_evolution.md       # v0.4～v0.6 训练架构演进
└─ version_history.md          # 全项目 Tag 与里程碑
```

具体运行说明放在对应工程目录内，避免在顶层重复并逐渐失真：训练见 `05_software/train/rc_mjlab/`，真机部署见 `05_software/real/`。

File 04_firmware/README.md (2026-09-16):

# 嵌入式固件

本目录用于保存运行在 MCU 或其他嵌入式控制器上的固件源码和构建工程。

编译生成的 `.hex`、`.bin`、`.elf`、`.axf` 等文件不进入源码目录，可在需要时作为 Release 附件发布。

当前 16DOF 主线尚未在本目录归档 MCU/Keil 工程；该目录是预留入口。8DOF 大疆 A 板 Keil 工程由 `8dof` 分支和 `v0.1.0` 保存。

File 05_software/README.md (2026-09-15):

# 软件

本目录保存 16DOF 轮足机器人的训练、仿真和真机软件演进。

```text
05_software/
├─ train/
│  └─ rc_mjlab/       # 训练、MJCF、MuJoCo、Sim2Sim 和本地 mjlab 依赖
└─ real/
   ├─ ik_real/        # IK 轨迹与早期真机控制
   ├─ sim2real/       # 第一代 Python 策略真机部署
   ├─ sim2real_v2/    # Python Sim2Real v2
   ├─ sim2real_ros2/  # ROS 2/C++ Sim2Real 初版
   ├─ sim2real_ros2_v2/ # ROS 2 导航原型及里程计演进
   └─ sim2real_ros2_v3/ # 最终比赛 ROS 2/C++ 部署
```

当前工作树按架构大版本同时保留三个 ROS 2 目录：无后缀目录是初版，`_v2` 是第二版演进的最终里程计快照，`_v3` 是 `last_not_slalom_1050` 最终比赛部署。各目录内部的小阶段仍可通过对应 Tag 恢复。

## 数据流

```text
MJCF + mjlab task
        |
        v
   PPO 训练策略
        |
        +----> MuJoCo 姿态 / IK / MPC 调试
        |
        +----> Sim2Sim 策略验证
        |
        +----> Python Sim2Real / v2 ----> 电机 / IMU
        |
        +----> ROS 2/C++ Sim2Real -----> CAN / IMU / 导航

IK real --------------------------------> 电机
```

`rc_mjlab` 是自包含工程。训练、MJCF、MuJoCo、Sim2Sim、导航工具和策略权重通过相对路径绑定，因此保留其内部布局，没有为了目录外观拆散。第一代完整闭环见 `v0.3.0`，第一份新版 MJCF 与训练框架见 `v0.4.0`，随机化增强版见 `v0.5.0`，比赛最终训练架构见 `v0.6.0`，后期 MuJoCo 工具集见 `v0.7.0`，后期 Sim2Sim 与比赛 Rough 策略见 `v0.8.0`，完整导航打点工具见 `v0.8.1`，Python Sim2Real v2 对应 `v0.9.0`，ROS 2/C++ 初版对应 `v0.10.0`，简单导航原型对应 `v0.11.0`，完整 Odin/TensorRT 与站姿调参对应 `v0.11.1`，纯里程计导航联调对应 `v0.12.0`，1050 分比赛最终部署对应 `v1.0.0`。

详细说明见：

- [`train/README.md`](train/README.md)
- [`real/README.md`](real/README.md)
- [`../01_doc/architecture/early_software_stack.md`](../01_doc/architecture/early_software_stack.md)

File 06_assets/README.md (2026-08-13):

# 媒体与测试结果

本目录用于保存 16DOF 轮足机器人的原创图片、演示视频、测试图表和比赛结果。

## 第一代 Sim2Real 真机验证

第一代 Sim2Real 真机验证

- 视频：[`videos/early_sim2real.mp4`](videos/early_sim2real.mp4)
- 阶段：第一代真机控制与 Sim2Real
- 时长：约 41 秒
- 画面：720 x 1280
- 编码：H.264/AAC，便于网页端和常用播放器播放

大体积视频和完整日志建议作为 Release 附件发布；体积较小、对版本说明有直接价值的演示视频可随对应版本提交。

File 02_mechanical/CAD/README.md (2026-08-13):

# SolidWorks 源文件

`solidworks/` 保留原始装配层级和文件名。

建议使用 `solidworks/WEEKDOG.SLDASM` 作为整机入口。`26版sw单件/` 包含组成整机的单件和子装配体，不应随意改名或拆散。

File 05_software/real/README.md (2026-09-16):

# 真机控制版本演进

本目录保存 16DOF 轮足机器人从早期 Python 闭环到 ROS 2 部署的真机控制演进。

## `ik_real`

基于几何逆运动学和轨迹插值的真机控制探索，不依赖强化学习策略。主要用于验证电机接口、关节映射和姿态轨迹。

## `sim2real`

第一代 Python 策略部署栈，包含：

- 53D 观测到 16D 动作的策略运行时
- 电机映射和真机 IO
- IMU 接入
- 站立初始化与平衡
- 运行时安全检查和阻尼刹车
- Web 调试界面
- 对齐、标定和独立检查工具

部署说明见 [`sim2real/README.md`](sim2real/README.md) 与 [`sim2real/DEPLOYMENT.md`](sim2real/DEPLOYMENT.md)。

## `sim2real_v2`

Python Sim2Real v2，保留 `53D -> 16D` 策略接口，并增加电机反馈新鲜度、Odin odom 诊断、命令平滑、Web 运行时诊断和安全监控工具，对应 `v0.9.0`。

部署说明见 [`sim2real_v2/README.md`](sim2real_v2/README.md) 与 [`sim2real_v2/DEPLOYMENT.md`](sim2real_v2/DEPLOYMENT.md)。

## ROS 2/C++ 版本线

### `sim2real_ros2`（初版，`v0.10.0`）

无后缀目录固定表示 ROS 2/C++ Sim2Real 初版：将策略热路径迁移为 50 Hz C++ 推理和 200 Hz CAN 电机循环，并加入 ROS 2 消息、命令仲裁、Nav2 与统一启动结构。原始快照未随工程保存 Odin ROS 2 驱动源码，依赖边界见 [`sim2real_ros2/README.md`](sim2real_ros2/README.md)。

### `sim2real_ros2_v2`（`v0.11.0`～`v0.12.0`）

在 `v0.11.0` 中，该目录是 ROS 2 Sim2Real v2 导航原型，增加简单导航节点、PCD 交互定位、任务点/任务序列和 Web 导航调试。

`v0.11.1` 在同一路径继续演进，首次归档完整 Odin 驱动、TensorRT、多策略切换和硬件诊断，并使用 `hip=0.670`、`knee=-1.390` 的调参站姿。

`v0.12.0` 仍在同一路径上形成里程计导航联调快照：固定纯里程计模式，加入 odom fallback 的 TF 冲突保护、A_min 路线和多地图工具；默认 Rough 策略为 `model_9600`，默认站姿回到比赛站姿。当前该目录保持 `v0.12.0` 快照，阶段说明见 [`sim2real_ros2_v2/README.md`](sim2real_ros2_v2/README.md)。

### `sim2real_ros2_v3`（最终比赛版；代码快照 `v1.0.0`，规范目录 `v1.1.0`）

第三版来自原始目录 `sim2real_ros2_v2(last_not_slalom_1050)`，整理时正式命名为 `sim2real_ros2_v3`。它是 1050 分比赛最终部署，包含 `model_6800` Rough、`model_84` Wall、最终路线、完整 Odin 驱动、CAN 和触控屏。部署说明见 [`sim2real_ros2_v3/README.md`](sim2real_ros2_v3/README.md)。

## 实机记录

第一代 Sim2Real 真机验证

该视频记录了这一阶段的早期真机测试，用于对应本目录中的第一代控制与部署实现。

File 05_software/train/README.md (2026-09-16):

# 强化学习与仿真工程

`rc_mjlab/` 保存 16DOF 轮足机器人的训练、MuJoCo、Sim2Sim 和导航工具累积工作树。历史训练架构由 Git Tag 保留，不在目录中复制 `old`、`new` 或 `final` 版本。

当前工作树由多个里程碑累积：训练主体以 `v0.6.0` 的 `best` 比赛架构为基础，`v0.7.0`～`v0.8.1` 依次补充 MuJoCo、Sim2Sim、比赛 Rough ONNX 和导航打点工具。训练过程可能先获得基模，再调整奖励、课程和环境参数继续训练；模型 checkpoint 的变化不等同于软件架构变化。

## 内容

- `src/robot`：Flat、Rough、Crawl 训练任务和自定义 MDP
- `mjcf`：轮足机器人 MuJoCo 模型和网格
- `sim2sim`：策略加载、交互控制和比赛地形验证
- `mujoco_sim`：不依赖训练循环的姿态、IK、动力学和 MPC 分析
- `tools/nav_tools`：地图/PCD 查看、航点编辑、路线检查和比赛路线数据
- `mjlab`：固定版本的本地训练框架依赖
- `model_rough.pt`：本阶段 Rough 策略权重
- `model_6800.onnx`：比赛最终使用的 Rough 策略
- `pyproject.toml`、`uv.lock`：Python 环境与依赖锁定

与 `v0.3.0` 相比，本版本更新了 MJCF 质量和惯性参数，并将 mjlab 上游基准从 `00409797` 更新到 `40f8d93e`。机械 CAD 未发生变化。

与 `v0.4.0` 相比，本版本没有再次修改 MJCF 和训练框架，只调整训练环境配置：投影重力噪声从 `±0.05` 扩大到 `±0.08`，最大动作延迟从 2 步增加到 4 步，扩大摩擦、刚度和阻尼随机化，增加腿部质量随机化与连续外力/力矩扰动。

`v0.6.0` 在 `v0.5.0` 之后转向比赛任务优化：降低部分过强随机化，加入分轴速度跟踪奖励、自适应指令课程、障碍地形释放课程、楼梯横向/偏航约束以及更完整的训练诊断。详细对比见 [`../../01_doc/training_evolution.md`](../../01_doc/training_evolution.md)。

`v0.7.0` 不修改比赛训练架构，增加独立 MuJoCo 工具；入口和参数边界见 [`rc_mjlab/mujoco_sim/README.md`](rc_mjlab/mujoco_sim/README.md)。

`v0.8.0` 继续保持训练架构和 MJCF 不变，归档后期 Sim2Sim 增量与比赛 Rough ONNX 策略；入口和归档边界见 [`rc_mjlab/sim2sim/README.md`](rc_mjlab/sim2sim/README.md)。

`v0.8.1` 补充完整导航打点工具和小体积预览点云；入口、路线清单和抽样边界见 [`rc_mjlab/tools/nav_tools/README.md`](rc_mjlab/tools/nav_tools/README.md)。

工程命令和任务说明见 [`rc_mjlab/README.md`](rc_mjlab/README.md)，本地依赖来源见 [`rc_mjlab/DEPENDENCIES.md`](rc_mjlab/DEPENDENCIES.md)。

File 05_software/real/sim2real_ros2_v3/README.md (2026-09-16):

# ROS 2 Sim2Real v3：最终比赛版

本目录由原始 `sim2real_ros2_v2(last_not_slalom_1050)` 整理而来，正式作为 ROS 2/C++ 第三版（v3），对应 RC_WheelLeg 在 RoboCon 仿生足式障碍赛使用的最终部署栈。`1050` 是比赛得分，不是模型编号；比赛 Rough 策略为 `model_6800.onnx`。

比赛代码快照首次归档于 `v1.0.0`，当时暂存于无后缀目录；`v1.1.0` 恢复无后缀初版并将本工程规范为 v3。训练架构和策略来源见 `v0.6.0`，比赛 Rough 模型首次归档见 `v0.8.0`，导航打点与路线演进见 `v0.8.1`，ROS 2 迁移过程见 `v0.10.0`～`v0.12.0`。

`v1.0.1` 只在比赛代码快照基础上补充机器人图片和比赛视频，没有改变本目录运行逻辑。

## 系统闭环

```text
Odin IMU / Odom ──> hardware bridge ──> RuntimeState
                                              |
导航 / 遥控 / 屏幕 ──> cmd mux ──> policy runtime (50 Hz)
                                              |
                                      RuntimeTarget
                                              |
                              hardware bridge / CAN (200 Hz)
```

核心约束：

- 53 维策略观测、16 维动作输出。
- Rough：`model_6800`，优先 TensorRT，失败时回退 ONNX Runtime。
- Wall：`model_84`，同样保留 TensorRT 与 ONNX 两种文件。
- Crawl：比赛配置使用解析 IK，不加载 Crawl RL 权重。
- 默认站姿：髋俯仰 `0.550`、膝关节 `-1.125`。
- 默认命令源：`NAV`；默认定位模式：`relocal`。

## 目录

```text
sim2real_ros2_v3/
├─ src/
│  ├─ sim2real_interfaces/  # RuntimeState / RuntimeTarget 消息
│  ├─ sim2real_common/      # 部署契约、滤波、平衡和安全监控
│  ├─ sim2real_hw/          # SocketCAN、IMU 和 200 Hz 电机热路径
│  ├─ sim2real_runtime/     # 策略、命令仲裁、导航、Web API
│  ├─ sim2real_nav2/        # Nav2 配置入口
│  ├─ sim2real_bringup/     # 统一参数和启动文件
│  └─ odin_ros_driver/      # Odin ROS 驱动（Apache-2.0）
├─ policies/                # 比赛实际使用的 Rough / Wall 模型
├─ map/                     # 比赛路线和抽样 PCD
├─ screen/                  # Orin 800×600 触控面板
├─ docs/                    # 架构、遥控、Web 和迁移说明
├─ Dockerfile
└─ start_sim2real.sh
```

## 构建与运行

目标环境是 Ubuntu 22.04、ROS 2 Humble 和 Jetson Orin。系统依赖和 Docker 流程见 [`DEPLOYMENT_GUIDE.md`](DEPLOYMENT_GUIDE.md)。

```bash
cd 05_software/real/sim2real_ros2_v3
colcon build --merge-install --cmake-args -DCMAKE_BUILD_TYPE=Release
./start_sim2real.sh
```

运行参数和模型/路线均使用工作区根目录相对路径，因此应从本目录启动。常用启动覆盖：

```bash
# 纯里程计模式，不等待 Odin 重定位地图
./start_sim2real.sh localization_mode:=odom \
  odin_config_file:=src/odin_ros_driver/config/control_command_odom.yaml

# 禁止驱动，仅做软件链路检查
./start_sim2real.sh launch_driver:=false launch_remote:=false
```

## 必须补充的部署资产

最终源目录配置引用了 Odin `map/1hao.bin`，但工作区备份中不存在这个文件；全盘检索也未找到同名文件。为避免用来源不明的 `.bin` 冒充比赛地图，本仓库不伪造该资产。

使用 `relocal` 前必须：

1. 从比赛 Orin 或 Odin 建图备份取得真实 `1hao.bin`。
2. 修改 `src/odin_ros_driver/config/control_command_relocal.yaml` 中的 `relocalization_map_abs_path` 为目标机绝对路径。
3. 核对文件哈希并在发布说明中补充来源。

缺少该文件时请使用 `localization_mode:=odom`，不要宣称重定位闭环已复现。地图和路线边界见 [`map/README.md`](map/README.md)。

## 归档边界

已保留：

- 最终六个 ROS 2 包、Odin 驱动源码、比赛设备标定参数和预编译 SDK 静态库。
- 最终 Rough/Wall ONNX 与比赛机 TensorRT engine。
- 五份最终工程路线、1 号场地抽样 PCD、屏幕 UI 和启动脚本。
- Odin 驱动 Apache-2.0 许可证。

未保留：

- 嵌套 `.git`、`__pycache__`、日志、备份、构建/安装目录。
- 未被比赛配置引用的候选模型与候选 TensorRT engine。
- 开发计划、任务草稿、重复地图工具和运行时轨迹。
- 原备份中大小为 0 的浏览器静态页面；HTTP JSON API 和屏幕 UI 源码仍保留。

TensorRT engine 与 JetPack、TensorRT 版本及 GPU 架构有关；其他机器应从同名 ONNX 重新生成，不应默认复用比赛 engine。模型哈希见 [`policies/README.md`](policies/README.md)。

## 安全与开源状态

- 真机运行前必须架空轮组验证 CAN 映射、方向、零位、急停和限幅。
- `deployment_contract.hpp` 是电机映射和动作缩放真值源；参考 YAML 不会自动修改 C++ 契约。
- 自研 ROS 包的 `package.xml` 仍保留原工程的 `Proprietary` 字段。迁移到 GitHub 公共开源前，需要由项目负责人选择许可证并统一修改；本次整理不代替权利人作许可证决定。
- 当前 Windows 环境只能做静态检查，不能证明 ROS 2、SocketCAN、Odin SDK 或 TensorRT 真机运行成功。

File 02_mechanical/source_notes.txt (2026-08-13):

机械设计采用26版本sw设计，装配，以及urdf导出，为减少sw装配出现问题，采用单件装配小件各个关节装配体，转step关节文件，step各关节装配总装配体方案

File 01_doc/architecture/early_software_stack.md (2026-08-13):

# 第一代软件闭环

第一代 16DOF 软件的目标是先打通“训练、仿真验证、真机执行”闭环，而不是在初期建立复杂的分布式系统。

## 训练与策略

`05_software/train/rc_mjlab` 使用本地修改的 mjlab 和 MuJoCo 模型训练轮腿混合策略。训练任务包括 Flat、Rough 和 Crawl，腿部 12 个关节输出位置目标，4 个轮子输出速度目标。

## MuJoCo 与 Sim2Sim

- `mujoco_sim` 用于不加载 RL 策略时的模型、动力学和控制调试。
- `sim2sim` 加载训练策略，在独立 MuJoCo 环境中验证观测、动作、地形和导航行为。
- 两者与训练任务共同使用 `rc_mjlab/mjcf`，避免早期模型定义不一致。

## 真机控制

- `ik_real` 先以逆运动学和轨迹插值验证电机控制链路。
- `sim2real` 再将训练策略部署到 Python 真机运行时，加入 IMU、站立、安全和 Web 调试。

## 阶段特点

这一版本的优势是链路完整、模块直观，便于快速验证；局限是训练、仿真和部署仍存在重复资源，Python 真机运行时的实时性和系统集成能力有限。这些问题推动了后续统一训练版本和 ROS 2/C++ 部署架构。

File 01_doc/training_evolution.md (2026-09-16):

# 训练代码演进

本项目将“训练代码架构”和“训练产生的模型 checkpoint”分别管理。代码、奖励、课程或观测契约发生变化时形成新的 Git 版本；同一架构下继续训练产生的模型编号作为实验和部署工件记录。

| 版本 | 来源快照 | 主要目的 |
| --- | --- | --- |
| `v0.4.0` | `uni_mjlab(1)` | 第一份完整的新 MJCF 与新 mjlab 训练工程 |
| `v0.5.0` | `uni_mjlab_new` | 扩大观测、延迟和动力学随机化，探索更强 Sim2Real 鲁棒性 |
| `v0.6.0` | `best` | 面向比赛越障重新设计奖励、课程、站姿和诊断体系 |

## 从随机化增强到比赛训练

`v0.6.0` 不是简单地继续增大 `v0.5.0` 的随机范围。实践中重新降低了部分噪声、延迟和动力学随机化强度，并把训练重点转向可控的比赛任务课程：

- 投影重力噪声由 `±0.08` 调回 `±0.05`。
- 腿和轮动作最大随机延迟由 4 步调回 2 步。
- 摩擦、刚度和阻尼随机化调回较窄范围。
- 移除该阶段的连续机身外力扰动与腿部质量随机化。
- 将 x、y 和 yaw 跟踪拆成独立奖励和独立指令课程。
- 障碍由课程逐步释放，高墙训练地形改为五道重复横墙。
- 增加楼梯侧向漂移和偏航漂移惩罚。
- 增加大量只用于训练评估的误差、轮速、姿态和接触指标。

这种调整反映的是从“广泛鲁棒性探索”转向“比赛场景定向优化”，不表示 `v0.5.0` 被删除；它仍由对应 Tag 完整保留。

## 模型与比赛部署

比赛训练可能先获得基模，再修改参数继续训练和筛选 checkpoint。最终关系为：

```text
训练代码架构：v0.6.0 / best
比赛 Rough 策略：model_6800.onnx
比赛真机工程：last_not_slalom_1050
比赛得分：1050
```

`model_6800.onnx` 是比赛最终部署工件，不用模型编号替代训练代码版本号。它已随比赛部署归档；当前规范目录为 `05_software/real/sim2real_ros2_v3/policies/`。

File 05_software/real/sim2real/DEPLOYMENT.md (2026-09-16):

# `sim2real` 部署说明

> 版本范围：第一代 Python Sim2Real（`v0.3.0`）。本文“当前”均指该快照。

## 模型

当前只使用：

- `policies/model_rough.pt`

## 模型契约

- `obs_dim = 53`
- `action_dim = 16`
- 单帧输入
- 无 `base_lin_vel`
- 无 `height_scan`

## 启动流程

1. 连接硬件
2. 使能电机
3. 从当前实测姿态起立
4. 进入 `stand_balance` 闭环站立
5. prime 当前观测
6. 进入 `50Hz` runtime

## 为什么这样改

- 之前版本在 `startup` 后只维持固定 `STAND_POSE`
- 实机上纯 PD 不足以持续抗姿态扰动
- 现在增加独立站立闭环，先保证身体支撑，再进入策略

## 运行开关

- `config.yaml > policy.enable_zero_cmd_suppression`
- `config.yaml > stand_balance.enabled`
- `config.yaml > policy.hold_zero_command_pose`
- `config.yaml > policy.command_release_s`

## 纯 Python 命令

默认前提：当前目录是 `05_software/real/sim2real/`

```bash
python -m pip install -r requirements-orin.txt
python tools/alignment_check.py --policy policies/model_rough.pt --manifest deployment_manifest.yaml
python tools/standalone_check.py
python main.py --dry-run
python main.py
python web/server.py --host 0.0.0.0 --port 8080
```

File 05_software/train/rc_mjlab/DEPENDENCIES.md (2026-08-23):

# 依赖说明

## Python 环境

- Python `>=3.10,<3.14`
- `uv` 依赖管理
- MuJoCo `3.8` 系列
- `mjlab[cu128]`
- PyTorch CUDA 12.8 环境
- `pynput`
- 后期 Sim2Sim 可选依赖：Pygame、ONNX Runtime
- 导航打点可选依赖：Pygame、Pillow

精确解析结果保存在 `uv.lock`。项目使用本地可编辑的 `mjlab`：

```toml
[tool.uv.sources]
mjlab = { path = "mjlab", editable = true }
```

## mjlab 来源

- 上游仓库：`https://github.com/mujocolab/mjlab.git`
- 基准提交：`40f8d93e31b589dccae78ba6aadfc4b74cd1e3fd`
- 基准日期：`2026-06-02`
- 上游许可证：Apache-2.0，许可证文件保留在 `mjlab/LICENSE`

本版本在该基准上保留 1 处本地修改：

1. `mjlab/src/mjlab/envs/mdp/dr/actuator.py`：为分组执行器补充名称到运行时执行器对象的解析，使 PD 增益和力矩限制随机化能够正确作用于轮腿机器人的执行器组。

本次归档保留修改后的完整工作树，但不包含上游 `.git`、本地缓存、生成日志和运行时临时文件。

## 基本入口

在 `05_software/train/rc_mjlab` 下执行：

```bash
uv sync
uv run train Robot-Flat-v0
uv run play Robot-Rough-v0
```

根 `uv.lock` 保留比赛训练环境的历史解析结果。后期 Sim2Sim 新增依赖单独保存在 `sim2sim/requirements.txt`，运行时叠加，避免重新锁定时升级历史 MuJoCo nightly：

```bash
uv run --with-requirements sim2sim/requirements.txt python sim2sim/nav_sim2sim.py
```

导航打点工具同样不修改历史锁文件：

```bash
uv run --with-requirements tools/nav_tools/requirements.txt python tools/nav_tools/nav_map_viewer.py
```

GPU、CUDA、MuJoCo development wheel 和驱动版本必须满足 `pyproject.toml` 与 `uv.lock` 的约束。

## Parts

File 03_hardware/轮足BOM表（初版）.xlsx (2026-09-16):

店铺名称 | 商品名称 | 规格/型号 | 数量 | 单价(元) | 实付款(元) | 类别
加急同步轮定制 | 非标同步轮 | 5M\S5M\AT5\T5\5GT 定做 | 22 | 10 | 220 | 传动件
苏州屿鹿传动设备 | 橡胶同步带 | HTD5M | 4 | 9.25 | 37 | 传动件
亿达金属定制加工 | 铝合金方管型材 | 四方形铝管（定制打孔） | 23 | 9.27 | 213.2 | 结构件
BWLBOND旗舰店 | 乐泰螺丝胶 | 乐泰222/50ml 低强度 | 1 | 76.78 | 76.78 | 耗材
数智电气企业店 | 德力西电气电工胶带 | 黑色10码 5卷 PVC防水耐高温 | 1 | 5.99 | 5.99 | 耗材
chg彩格旗舰店 | PETG耗材3D打印线材 | 无线盘蓝-蓝色 1KG 1.75mm | 1 | 23.61 | 23.61 | 耗材
chg彩格旗舰店 | PETG耗材3D打印线材 | 有线盘蓝-蓝色 1KG 1.75mm | 1 | 23.61 | 23.61 | 耗材
chg彩格旗舰店 | PETG耗材3D打印线材 | 有线盘蓝-橙色 1KG 1.75mm | 1 | 27.05 | 27.05 | 耗材
海龙王模型店 | Radiolink乐迪遥控器 | AT9S PRO标配+控电+充电器+控包 | 1 | 574.03 | 574.03 | 遥控器，前期使用较多，可换用平替型号
力克电动滑板车配件仓库 | 儿童车8寸轮胎 | 200x45加厚内外胎 | 1 | 27 | 29.78 | 工具/其他
力克电动滑板车配件仓库 | 儿童车8寸轮胎 | 200x45加厚内外胎 | 3 | 30 | 90 | 工具/其他
星途千舟 | XT30总线中心板分电板 | 中心板 送XT60 | 1 | 31.6 | 31.6 | 电子元器件
澳凯森旗舰店 | GH1.25mm带锁扣胶壳 | GH1.25-2P胶壳带锁扣(50个) | 1 | 1.4 | 9.6 | 电子元器件
澳凯森旗舰店 | GH1.25mm带锁扣胶壳 | GH1.25-4P胶壳带锁扣(50个) | 1 | 2.7 |  | 电子元器件
澳凯森旗舰店 | GH1.25簧片/压线端子 | GH1.25簧片/压线端子(100个) | 1 | 2.5 |  | 电子元器件
丰枝电子 | Amass XT30带信号针插头 | XT30U(2+2)-F母头(信号焊接款) | 10 | 1.98 | 21.8 | 电子元器件
三利佳电子 | GH1.25mm电子线 | 黑色 500mm GH1.25双头(10条) | 1 | 1.45 | 7.01 | 电子线材
三利佳电子 | GH1.25mm电子线 | 黑色 200mm GH1.25双头(10条) | 1 | 0.78 |  | 电子线材
三利佳电子 | GH1.25mm电子线 | 红色 200mm GH1.25双头(10条) | 1 | 0.78 |  | 电子线材
三利佳电子 | GH1.25mm电子线 | 黑色 300mm GH1.25双头(10条) | 1 | 1 |  | 电子线材
阳光模型上海DIY模型配件 | XT30延长线转接线 | XT30U黑 公转母 16AWG | 8 | 14.2 | 113.56 | 电子线材
德熙电子 | CyberGear微电机连接线 | 双直母头18号硅胶线30cm | 6 | 14.5 | 131 | 电子线材
德熙电子 | CyberGear微电机连接线 | 双直母头18号硅胶线20cm | 4 | 11 |  | 电子线材
达妙科技企业店 | 关节电机配线 | XT30(2+2)双端200mm | 1 | 14 | 30 | 电子线材
德熙电子 | CyberGear连接线 | 双直母头18号硅胶线1米 XT30(2+2) | 3 | 19.33 | 65.19 | 电子线材
三利佳电子 | GH1.25mm电子线 | 黑色 500mm GH1.25双头(10条) | 1 | 1.45 | 8.91 | 电子线材
三利佳电子 | GH1.25mm电子线 | 红色 500mm GH1.25双头(10条) | 2 | 1.45 |  | 电子线材
三利佳电子 | GH1.25mm电子线 | 黑色 200mm GH1.25双头(10条) | 1 | 0.78 |  | 电子线材
三利佳电子 | GH1.25mm电子线 | 红色 200mm GH1.25双头(10条) | 1 | 0.78 |  | 电子线材
泰州欧力电器设备 | 航模耐高温特软硅胶线 | 黑色18AWG 1m 0.75平方 | 6 | 1.53 | 9.18 | 电子线材
泰州欧力电器设备 | 航模耐高温特软硅胶线 | 红色18AWG 1m 0.75平方 | 3 | 1.53 |  | 电子线材
深圳市优信电子科技 | 红黑并线 | 红黑RVB2*1 0.5平方 双色铜芯护套线1米 | 2 | 2 | 5.5 | 电子线材
阳光模型上海DIY模型配件 | XT60插头并联线分接线 | XT60H并联线(第2公并1母,12AWG金黑,3.4平方) 10cm | 1 | 17.5 | 17.5 | 电子线材
创禾良品电子科技 | XT60插头公母线带线 | XT60母头12AWG 3.4平方 10条 | 1 | 3.9 | 3.9 | 电子线材
暖熙优品 | CyberGear微电机连接线 | 双直母头18号硅胶线50cm XT30(2+2) | 4 | 17.6 | 128.4 | 电子线材
暖熙优品 | CyberGear微电机连接线 | 双直母头18号硅胶线30cm XT30(2+2) | 4 | 14.5 |  | 电子线材
飞飞模型 | 航模锂电池 | 22.2V/6S XT60 | 1 | 218.22 | 218.22 | 电源
飞起来Jumbo Power | 航模21700锂电池 | 6S平铺22.2V A品电芯 | 1 | 197 | 197 | 电源
正泰电器正品销售中心 | 空气开关带漏电保护器 | 2P 额定电流100A | 1 | 32.46 | 32.46 | 电气件
易稳科技 | EVEPS车载监控摄像头电源 | 24V转12V 中铝Y1 降压变压器 | 1 | 30 | 30 | 电气件
RobStride Dynamics | 灵足时代关节电机 | 17nm双编版（RS02） | 2 | 629 | 1258 | 电机
RobStride Dynamics | 灵足时代关节电机 | 系列套餐组合（含官方调试工具） | 1 | 665 | 665 | 电机及驱动
RobStride Dynamics | 灵足时代关节电机 | ROBSTRIDE02 17nm双编版 | 5 | 629 | 3145 | 电机
闲鱼二手 | 灵足时代关节电机 | ROBSTRIDE02 | 8 | 380 | 3040 | 电机
达妙科技 | USB转CAN | 双路FDCAN，CNC外壳 | 1 | 109 | 109 | 驱动
达妙科技 | USB转CAN | 单路，非FDCAN，v3.0 | 1 | 109 | 109 | 驱动（早期）
辽宁全景智能科技 | 碳纤维板 | 16自由度碳纤维身子板 | 2 | 80 | 160 | 结构件
嘉立创金属3d打印 | 结构件 | 316L | 1 | 1261.26 | 1261.26 | 结构件(可通过拆分零件来降低成本)
铨洲智造 | 结构件 | 6061 | 1 | 694 | 694 | 结构件
seeedstudio旗舰店 | Orin nano | Jetson Orin nano 8g+256g硬盘 | 1 | 2300 | 2300 | 上位机（已涨价，可通过RK3588等替换）
留形科技官方 | 空间记忆模组 | odin1 | 1 | 3000 | 3000 | 导航定位模块（可通过便宜的其他方案，如二手工业级IMU+拆机雷达+算法代替）
固万基官方旗舰店 | 304不锈钢杯头内六角螺丝 | M3*16[50个] | 1 | 2.72 | 39.05 | 紧固件
固万基官方旗舰店 | 304不锈钢杯头内六角螺丝 | M3*10[50个] | 1 | 2.04 |  | 紧固件
固万基官方旗舰店 | 304不锈钢杯头内六角螺丝 | M3*14[50个] | 1 | 2.49 |  | 紧固件
固万基官方旗舰店 | 304不锈钢杯头内六角螺丝 | M3*18[50个] | 2 | 2.87 |  | 紧固件
固万基官方旗舰店 | 304不锈钢杯头内六角螺丝 | M3*22[50个] | 1 | 3.4 |  | 紧固件
固万基官方旗舰店 | 304不锈钢杯头内六角螺丝 | M4*10[40个] | 1 | 3.01 |  | 紧固件
固万基官方旗舰店 | 304不锈钢杯头内六角螺丝 | M4*14[50个] | 1 | 4.61 |  | 紧固件
固万基官方旗舰店 | 304不锈钢杯头内六角螺丝 | M4*16[20个] | 2 | 2.08 |  | 紧固件
固万基官方旗舰店 | 304不锈钢杯头内六角螺丝 | M4*18[20个] | 2 | 2.23 |  | 紧固件
固万基官方旗舰店 | 304不锈钢杯头内六角螺丝 | M5*10[20个] | 2 | 2.04 |  | 紧固件
固万基官方旗舰店 | 304不锈钢杯头内六角螺丝 | M5*14[20个] | 1 | 2.34 |  | 紧固件
天诚五金TC | 316不锈钢锁紧螺母 | M5 [316不锈钢]-50只 | 1 | 5.25 | 21.04 | 紧固件
天诚五金TC | 316不锈钢锁紧螺母 | M4 [316不锈钢]-50只 | 1 | 4.69 |  | 紧固件
天诚五金TC | 316不锈钢锁紧螺母 | M3 [316不锈钢]-50只 | 1 | 4.58 |  | 紧固件
天诚五金TC | 316不锈钢锁紧螺母 | M5 [316不锈钢]-50只 | 1 | 5 | 20.04 | 紧固件
天诚五金TC | 316不锈钢锁紧螺母 | M3 [316不锈钢]-50只 | 1 | 4.36 |  | 紧固件
天诚五金TC | 316不锈钢锁紧螺母 | M4 [316不锈钢]-50只 | 1 | 4.47 |  | 紧固件
天诚五金TC | 304不锈钢锁紧螺母 | M8 [304不锈钢]-20只 | 2 | 3.11 |  | 紧固件
金超官方旗舰店 | 304不锈钢内六角螺丝 | M5*45 [20个] | 2 | 4.41 | 20.33 | 紧固件
金超官方旗舰店 | 304不锈钢内六角螺丝 | M5*30 [20个] | 2 | 3.28 |  | 紧固件
金超官方旗舰店 | 304不锈钢尼龙锁紧螺母 | M5(50个)加厚304 | 1 | 5.16 |  | 紧固件
固万基官方旗舰店 | 内六角螺丝12.9级高强度 | M4*20[50个] | 1 | 4.04 | 11.06 | 紧固件
固万基官方旗舰店 | 内六角螺丝12.9级高强度 | M3*40[50个] | 1 | 7.02 |  | 紧固件
天卓五金官方旗舰店 | 12.9级高强度内六角螺丝 | M3*40-20个 | 1 | 1.44 | 1.44 | 紧固件
 |  |  |  |  |  | 纯16dof大致成本 1.8w左右，结构件计算含试错成本，若上位机和定位模块和遥控器和电机等换用替代方案可以再低
8自由度串联版本 |  |  | 含未用于后期16DOF的材料)
大疆官方 | Dji 开发板A型 | Dji 开发板A型 | 1 | 429 | 429 | 下位机（8dof使用）
塔克创新品牌店 | 高速无线DAP调试器 | DAPLink仿真器+杜邦线 | 1 | 46 | 49.8 | 烧录器
塔克创新品牌店 | 高速无线DAP调试器 | DAPLink仿真器+杜邦线 | 1 | 46 | 49.8 | 烧录器
达妙科技 | USB转CAN | 单路，非FDCAN，v3.0 | 1 | 60 | 60 | 驱动（早期）
飞起来Jumbo Power | 航模21700锂电池 | 6S平铺22.2V A品电芯 | 1 | 197 | 197 | 电源
海龙王模型店 | Radiolink乐迪遥控器 | AT9S PRO标配+控电+充电器+控包 | 1 | 574.03 | 574.03 | 遥控器，前期使用较多，可换用平替型号
加急同步轮定制 | 非标同步轮 | 5M\S5M\AT5\T5\5GT 定做 | 22 | 10 | 220 | 传动件
苏州屿鹿传动设备 | 橡胶同步带 | HTD5M | 4 | 9.25 | 37 | 传动件
亿达金属定制加工 | 铝合金方管型材 | 四方形铝管（定制打孔） | 23 | 9.27 | 213.2 | 结构件
chg彩格旗舰店 | PETG耗材3D打印线材 | 离线蓝-灰色 1KG 1.75mm | 1 | 27.05 | 27.05 | 耗材
chg彩格旗舰店 | PETG耗材3D打印线材 | 无线蓝-黑色 1KG 1.75mm | 1 | 21.81 | 21.81 | 耗材
chg彩格旗舰店 | PETG耗材3D打印线材 | 可拆线盘-白色 2卷装 1.75mm | 1 | 48.99 | 48.99 | 耗材
chg彩格旗舰店 | PETG耗材3D打印线材 | 有线蓝-白色 1KG 1.75mm | 1 | 22.53 | 22.53 | 耗材
达妙科技企业店 | 关节电机配线 | XT30 2+2转GH1.25+XT30 | 8 | 9 | 308 | 电子线材
达妙科技企业店 | 关节电机配线 | GH1.25-4pin异面线100mm | 3 | 3 |  | 电子线材
达妙科技企业店 | 关节电机配线 | XT30(2+2)双端200mm | 8 | 14 |  | 电子线材
达妙科技企业店 | 关节电机配线 | XT30双端200mm | 8 | 8 |  | 电子线材
达妙科技企业店 | 关节电机配线 | GH1.25-2pin异面线300mm | 10 | 3 |  | 电子线材
阳光模型上海DIY模型配件 | XT60插头并联线分接线 | XT60H并联线(第2马并1公,12AWG红黑,3.4平方) 15cm | 1 | 21.39 | 21.39 | 电子线材
嘉立创金属3d打印 | 结构件 | 316L | 1 | 595.04 | 595.04 | 结构件
铨洲智造 | 结构件 | 6061 | 1 | 153.6 | 153.6 | 结构件
固万基官方旗舰店 | 304不锈钢杯头内六角螺丝 | M3*16[50个] | 1 | 2.76 | 2.76 | 紧固件
固万基官方旗舰店 | 304不锈钢防松螺母 | 316材质M8(10只) | 2 | 3.47 | 3.47 | 紧固件
固万基官方旗舰店 | 304不锈钢六角螺母 | 316材质M8[10颗] | 3 | 2.76 | 2.76 | 紧固件
固万基官方旗舰店 | 304不锈钢杯头内六角螺丝 | M4*18[20个] | 2 | 2.26 | 2.26 | 紧固件
固万基官方旗舰店 | 304不锈钢杯头内六角螺丝 | M4*10[40个] | 1 | 3.06 | 3.06 | 紧固件
固万基官方旗舰店 | 304不锈钢杯头内六角螺丝 | M3*22[50个] | 1 | 3.45 | 3.45 | 紧固件
固万基官方旗舰店 | 304不锈钢杯头内六角螺丝 | M5*10[20个] | 2 | 2.07 | 2.07 | 紧固件
固万基官方旗舰店 | 304不锈钢杯头内六角螺丝 | M4*16[20个] | 2 | 2.11 | 2.11 | 紧固件
固万基官方旗舰店 | 304不锈钢杯头内六角螺丝 | M3*14[50个] | 1 | 2.52 | 2.52 | 紧固件
固万基官方旗舰店 | 304不锈钢杯头内六角螺丝 | M3*10[50个] | 1 | 2.07 | 2.07 | 紧固件
固万基官方旗舰店 | 304不锈钢杯头内六角螺丝 | M4*14[50个] | 1 | 4.67 | 4.67 | 紧固件
固万基官方旗舰店 | 304不锈钢杯头内六角螺丝 | M3*18[50个] | 2 | 2.91 | 2.91 | 紧固件
固万基官方旗舰店 | 8.8级高强度内六角螺丝 | M8*35[20只]全牙 | 2 | 3.75 | 3.75 | 紧固件
固万基官方旗舰店 | 304不锈钢杯头内六角螺丝 | M5*14[20个] | 1 | 2.37 | 2.37 | 紧固件
固万基官方旗舰店 | 内六角螺丝12.9级高强度 | M3*30[50个] | 1 | 4.53 | 4.53 | 紧固件
固万基官方旗舰店 | 内六角螺丝12.9级高强度 | M3*8[50个] | 1 | 2.51 | 41.23 | 紧固件
固万基官方旗舰店 | 内六角螺丝12.9级高强度 | M4*25[50个] | 1 | 3.81 |  | 紧固件
固万基官方旗舰店 | 内六角螺丝12.9级高强度 | M3*40[50个] | 1 | 5.67 |  | 紧固件
固万基官方旗舰店 | 内六角螺丝12.9级高强度 | M3*12[50个] | 1 | 2.64 |  | 紧固件
固万基官方旗舰店 | 内六角螺丝12.9级高强度 | M4*22[50个] | 1 | 3.6 |  | 紧固件
天卓五金官方旗舰店 | 12.9级黑色螺丝细牙螺母 | M5(50只)12.9级 | 1 | 2.46 | 8.51 | 紧固件
天卓五金官方旗舰店 | 12.9级黑色螺丝细牙螺母 | M4(50只)12.9级 | 1 | 2.04 |  | 紧固件
天卓五金官方旗舰店 | 12.9级高强度内六角螺丝 | M6*12-50个 | 1 | 2.25 |  | 紧固件
天卓五金官方旗舰店 | 12.9级黑色螺丝细牙螺母 | M6(20个)12.9级 | 1 | 1.76 |  | 紧固件
天卓五金官方旗舰店 | 黑色平垫片GB97 | M5*15*1.2加大(25个) | 1 | 4.74 | 62.44 | 紧固件
天卓五金官方旗舰店 | 黑色平垫片GB97 | M4*9*0.8-50个 | 1 | 1.95 |  | 紧固件
天卓五金官方旗舰店 | 黑色平垫片GB97 | M3*7*0.5-100个 | 1 | 2.94 |  | 紧固件
天卓五金官方旗舰店 | 黑色六角螺母 | M4(50只)12.9级 | 1 | 2.39 |  | 紧固件
天卓五金官方旗舰店 | 黑色六角螺母 | M5(100个)8.8级 | 1 | 3.62 |  | 紧固件
天卓五金官方旗舰店 | 黑色六角螺母 | M3(100个)8.8级 | 1 | 2.44 |  | 紧固件
天卓五金官方旗舰店 | 12.9级高强度内六角螺丝 | M5*25-50个 | 1 | 5.09 |  | 紧固件
天卓五金官方旗舰店 | 12.9级高强度内六角螺丝 | M5*40-20个 | 1 | 3.34 |  | 紧固件
天卓五金官方旗舰店 | 12.9级高强度内六角螺丝 | M5*30-50个 | 1 | 6.62 |  | 紧固件
天卓五金官方旗舰店 | 12.9级高强度内六角螺丝 | M5*12-50个 | 1 | 3.52 |  | 紧固件
澳凯森旗舰店 | GH1.25带锁扣胶壳 | GH1.25-4P胶壳带锁扣(50个) | 1 | 2.7 | 7.1 | 电子元器件
澳凯森旗舰店 | GH1.25带锁扣胶壳 | GH1.25-2P胶壳带锁扣(50个) | 1 | 1.4 |  | 电子元器件

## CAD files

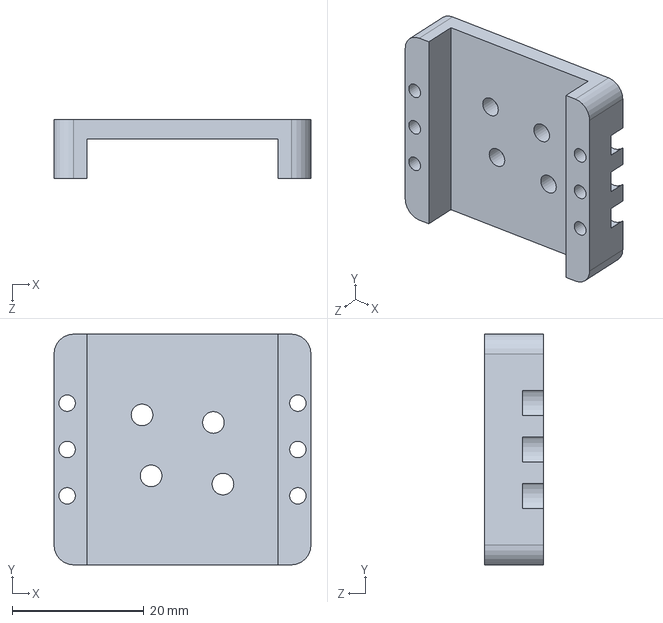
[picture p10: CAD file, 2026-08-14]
02_mechanical/CAD/solidworks/26版sw单件/电机连接4.11 SLDPRT.SLDPRT
39.0 x 35.1 x 9.00 mm

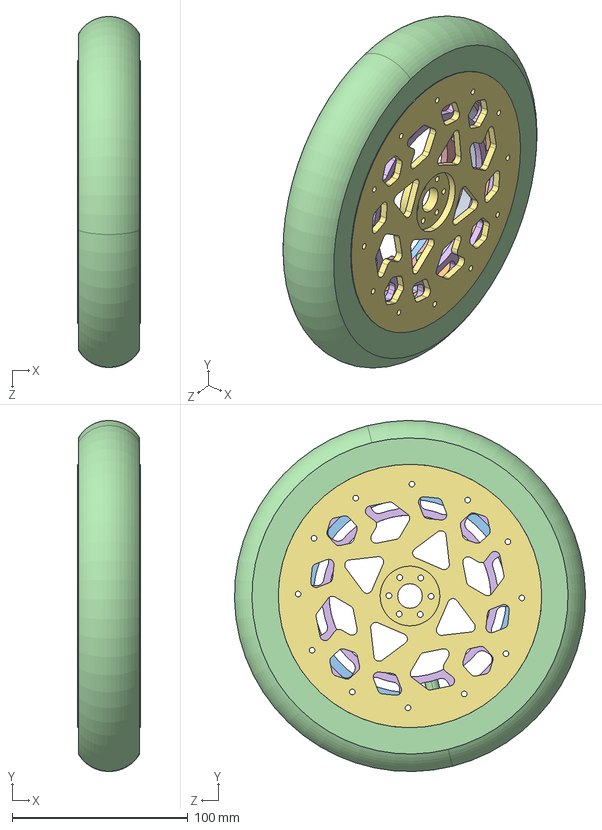
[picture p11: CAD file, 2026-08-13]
02_mechanical/STEP/新充气轮.STEP
36.0 x 199.9 x 199.9 mm
轮毂.stp
轮毂-板子.stp x 2
夹板-内测.stp
胎.stp
轮毂-打印件-1.stp
轮毂-打印件 - 2.stp
新轮毂无圆角

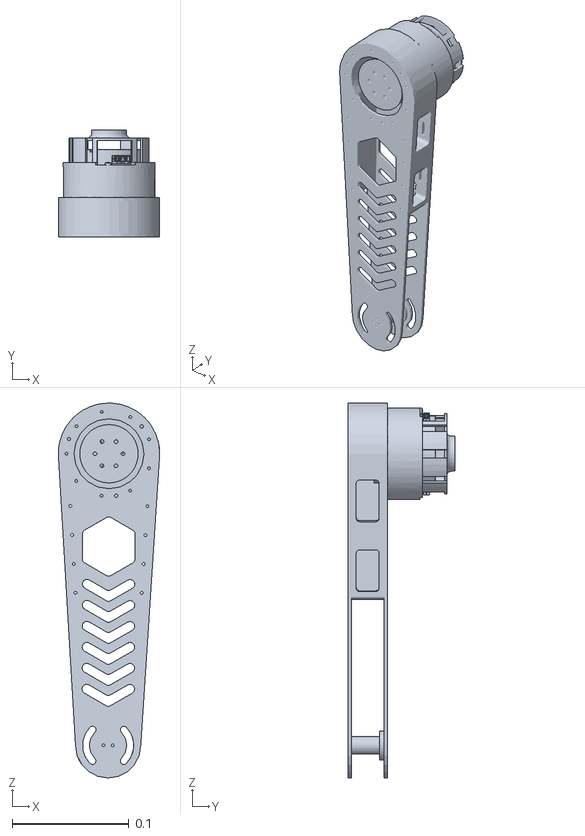
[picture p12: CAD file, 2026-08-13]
05_software/real/sim2real_v2/mjcf/meshes/fr_hip_pitch_Link.STL
0.087 x 0.0917 x 0.321

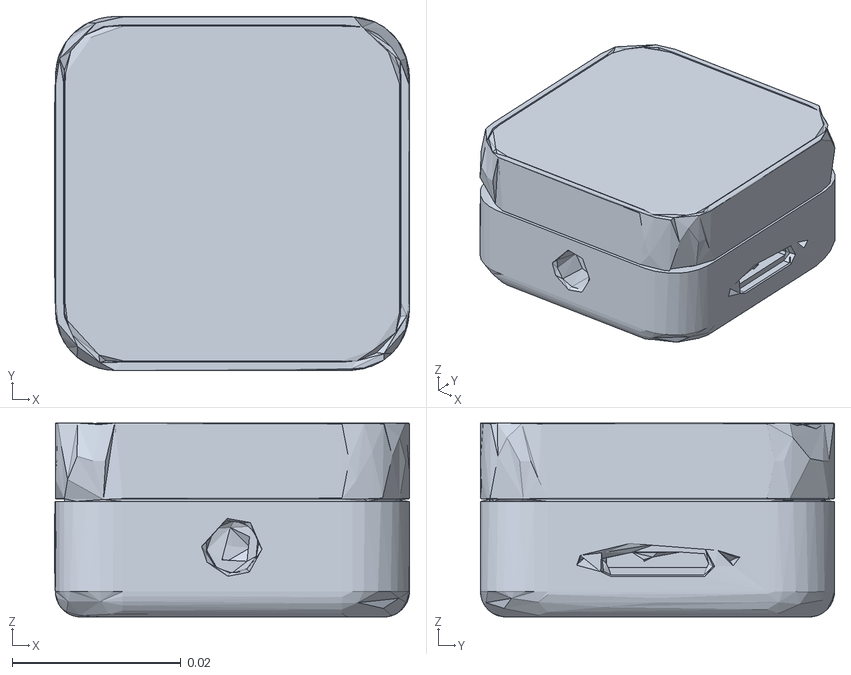
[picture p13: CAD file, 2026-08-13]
05_software/train/rc_mjlab/mjlab/src/mjlab/asset_zoo/robots/i2rt_yam/xmls/assets/d405.stl
0.0421 x 0.042 x 0.023

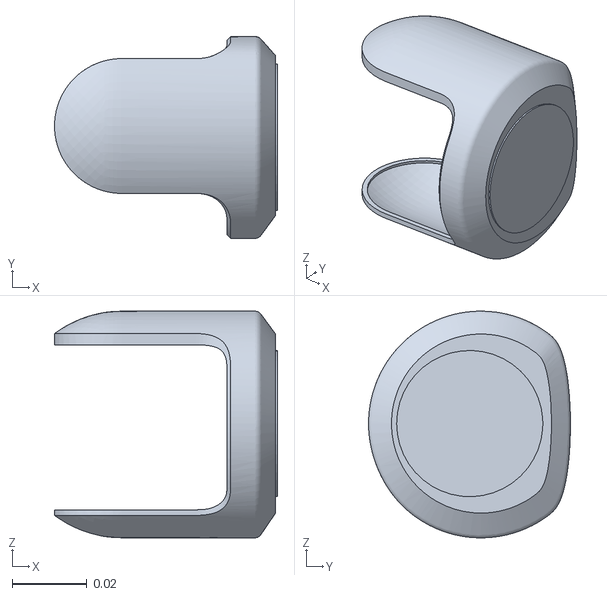
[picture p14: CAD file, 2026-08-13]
05_software/train/rc_mjlab/mjlab/src/mjlab/asset_zoo/robots/unitree_g1/xmls/assets/right_wrist_yaw_link.STL
0.0595 x 0.0539 x 0.0605

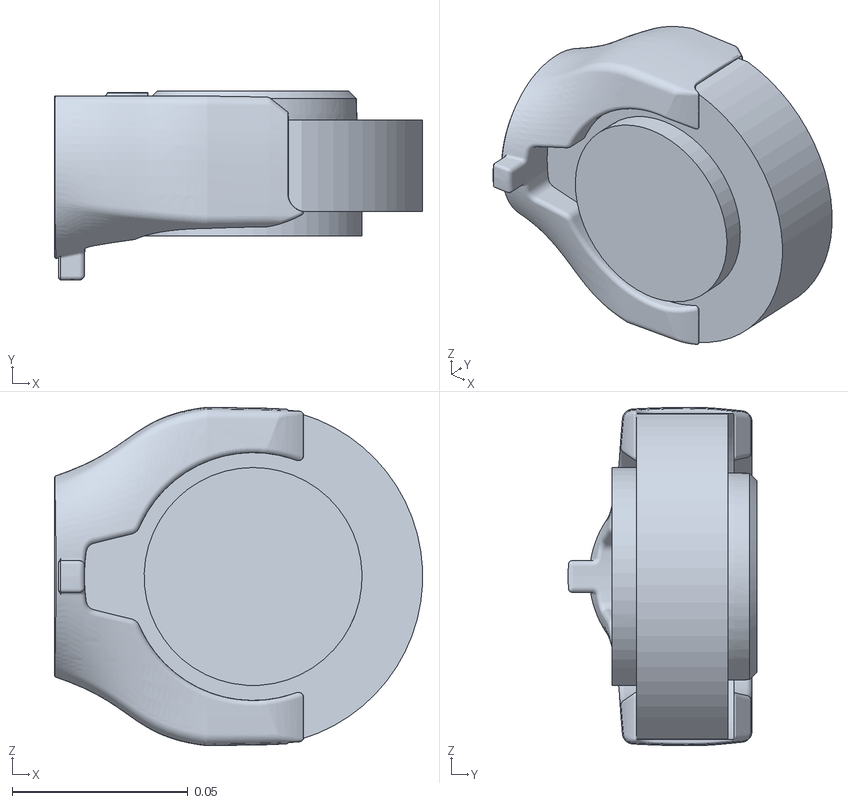
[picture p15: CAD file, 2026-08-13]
05_software/train/rc_mjlab/mjlab/src/mjlab/asset_zoo/robots/unitree_go1/xmls/assets/hip.stl
0.105 x 0.0538 x 0.0963

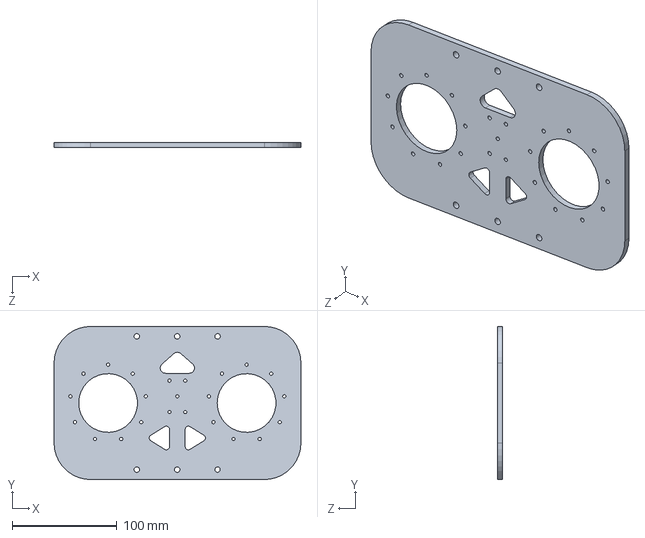
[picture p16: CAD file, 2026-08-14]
02_mechanical/CAD/solidworks/26版sw单件/新身子板6.圆角SLDPRT.SLDPRT
235.4 x 146.0 x 5.00 mm

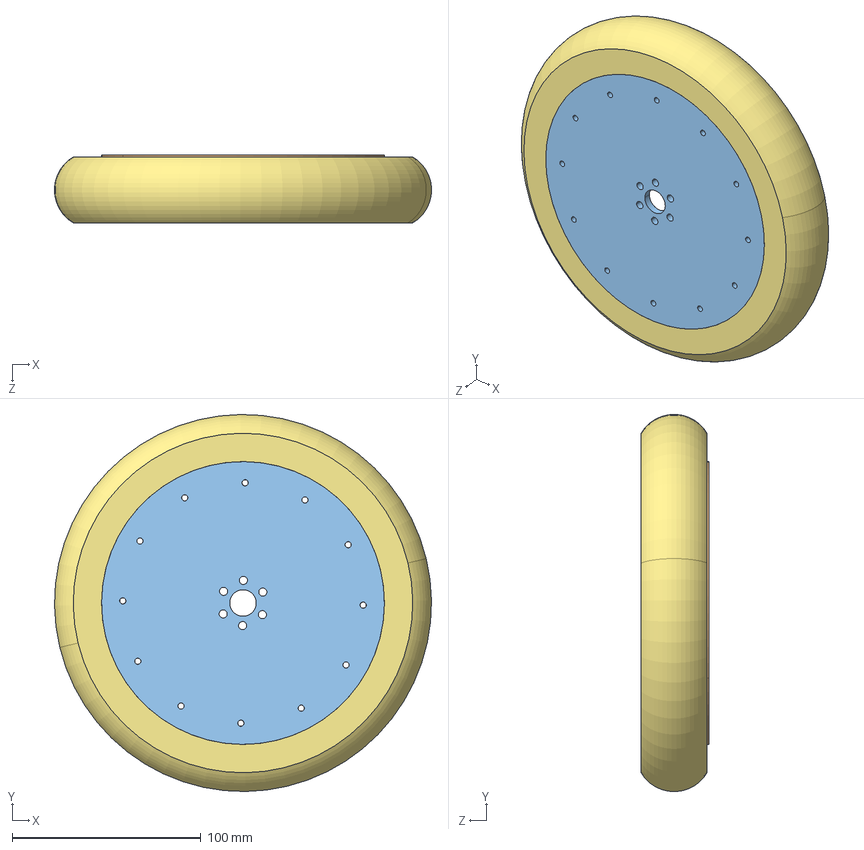
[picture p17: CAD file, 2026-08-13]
02_mechanical/STEP/轮子.STEP
199.9 x 199.9 x 36.0 mm
外侧轮毂2.step x 2
内侧轮毂1.step
新轮毂玻纤板.step
3D打印中间轮毂.step
3D打印外2.step
内侧轮毂2.step
轮胎.step

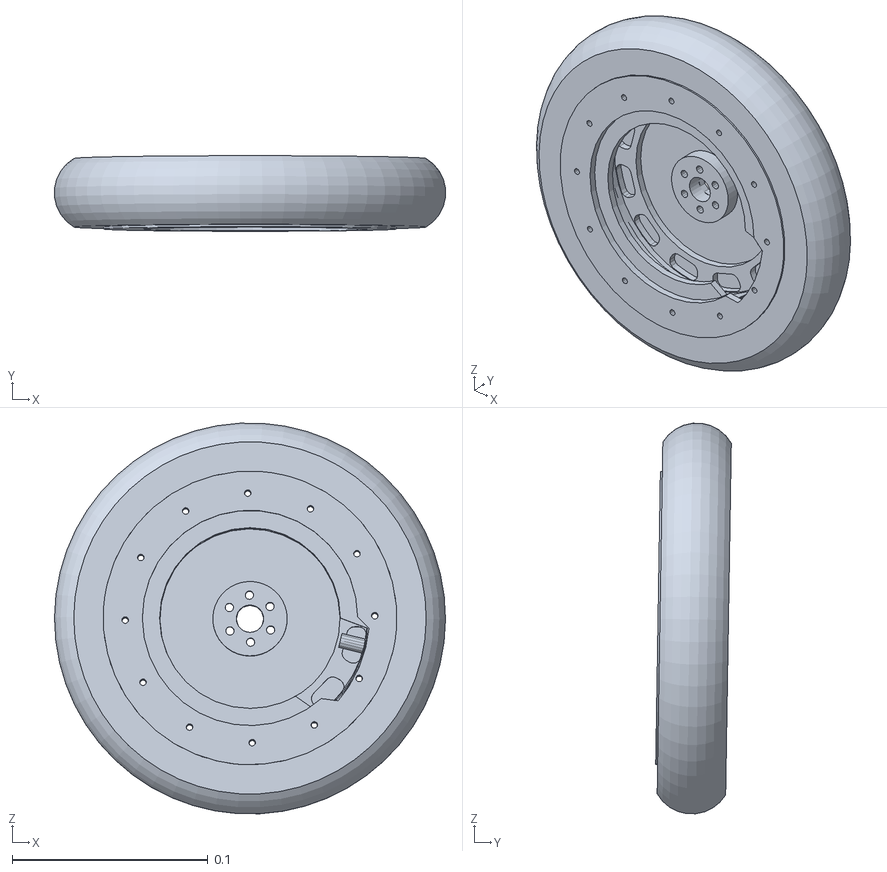
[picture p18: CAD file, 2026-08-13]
05_software/real/sim2real_v2/mjcf/meshes/rl_wheel_Link.STL
0.2 x 0.0386 x 0.199

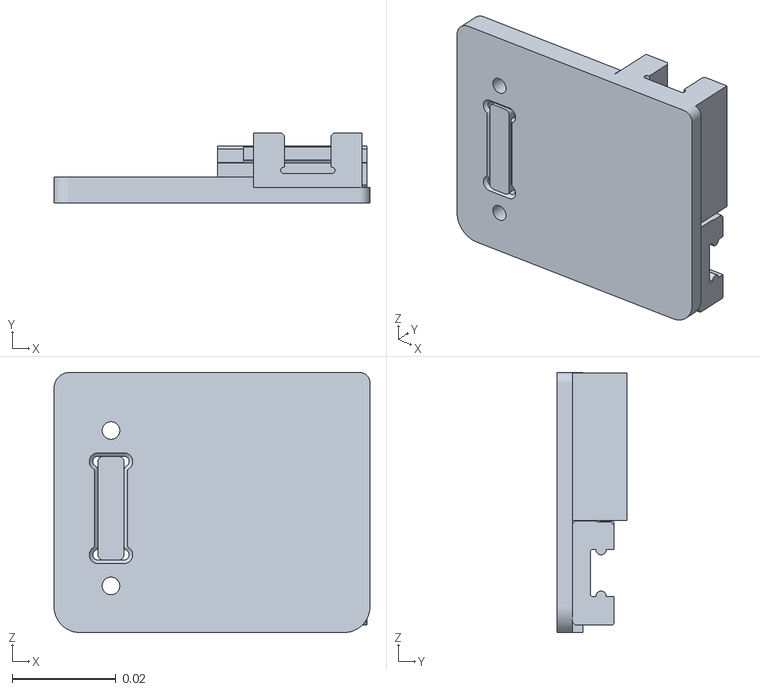
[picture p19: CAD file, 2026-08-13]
05_software/train/rc_mjlab/mjlab/src/mjlab/asset_zoo/robots/i2rt_yam/xmls/assets/model2__16.stl
0.061 x 0.0135 x 0.0502

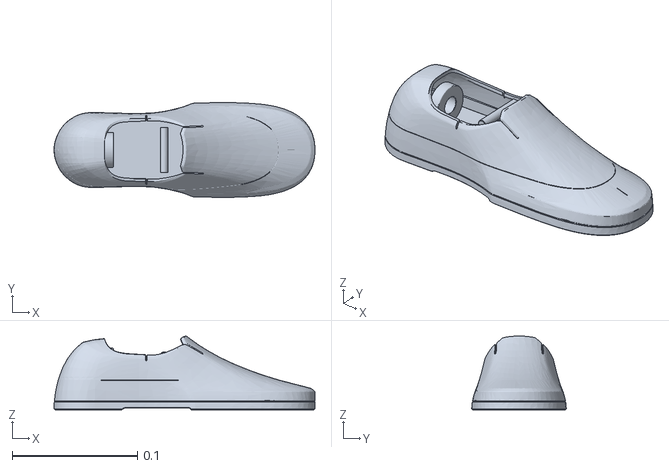
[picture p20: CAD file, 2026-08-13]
05_software/train/rc_mjlab/mjlab/src/mjlab/asset_zoo/robots/unitree_g1/xmls/assets/left_ankle_roll_link.STL
0.208 x 0.0756 x 0.059

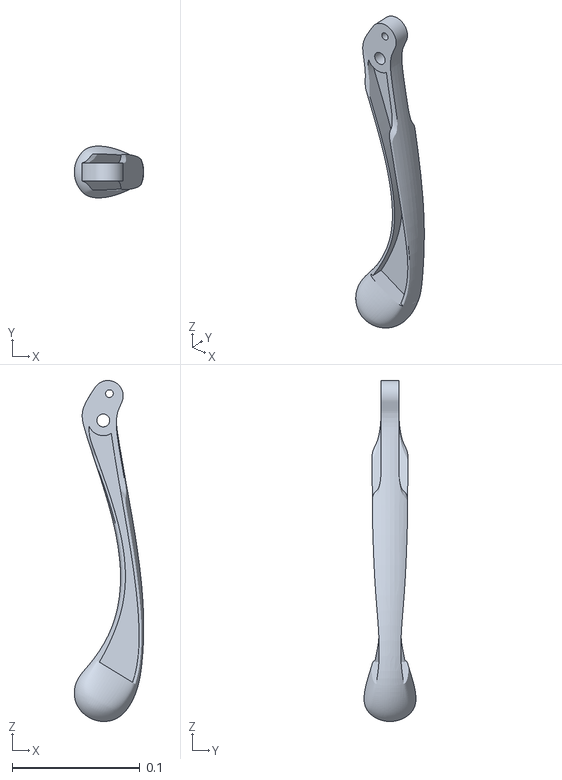
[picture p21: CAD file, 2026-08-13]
05_software/train/rc_mjlab/mjlab/src/mjlab/asset_zoo/robots/unitree_go1/xmls/assets/calf.stl
0.0543 x 0.0405 x 0.266

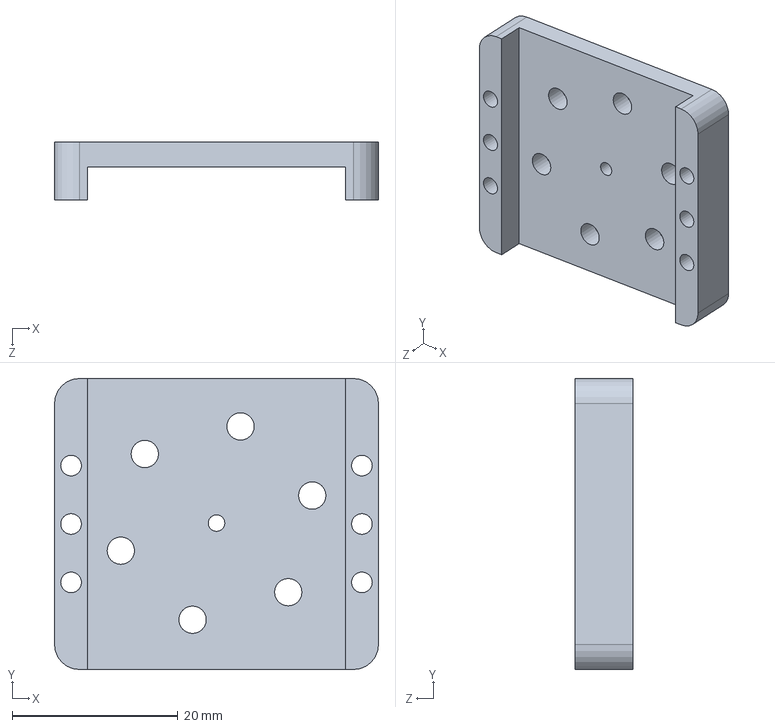
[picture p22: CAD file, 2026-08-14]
02_mechanical/CAD/solidworks/26版sw单件/电机连接3.3加宽SLDPRT.SLDPRT
39.0 x 35.1 x 7.00 mm

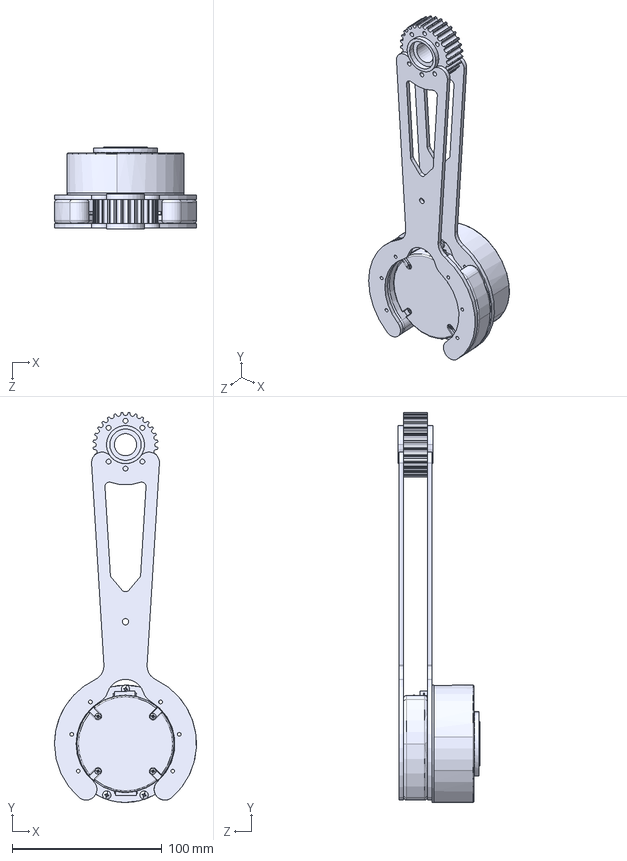
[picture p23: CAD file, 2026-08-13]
02_mechanical/STEP/轮小腿.STEP
95.0 x 260.8 x 54.6 mm
轮足小腿板 x 2
SOLID-183013_1.stp.STEP x 2
BOARD-17_1.stp.STEP
1_1_06_EB673-516_1.stp.STEP
1_1_02_EB671-502_1.stp.STEP
1_1_04_EB672-503_1.stp.STEP
1_2_05_QT-647_1.stp.STEP x 3
1_1_31_PL674-504_1.stp.STEP
1_2_04_670601_1.stp.STEP
1_2_06_000392_1.stp.STEP
1_2_05_QT-170_1.stp.STEP x 4
1_1_06_EB673-524_1.stp.STEP
1_2_05_020051_1.stp.STEP x 4
1_2_05_030080_1.stp.STEP x 3
下带轮 2.0
轮足小腿板2.1

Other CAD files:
02_mechanical/CAD/solidworks/26版sw单件/RS02.SLDASM
02_mechanical/CAD/solidworks/26版sw单件/ROBOCON.SLDASM
05_software/real/sim2real_v2/mjcf/meshes/rl_hip_pitch_Link.STL
05_software/train/rc_mjlab/mjlab/src/mjlab/asset_zoo/robots/i2rt_yam/xmls/assets/model2__11.stl
02_mechanical/CAD/solidworks/26版sw单件/21 15 4的轴承 2.0.SLDPRT
02_mechanical/CAD/solidworks/26版sw单件/5m同步带1 2.0.SLDPRT
02_mechanical/CAD/solidworks/26版sw单件/上带轮.SLDPRT
02_mechanical/CAD/solidworks/26版sw单件/下带轮.15.SLDPRT
02_mechanical/CAD/solidworks/26版sw单件/下带轮挡圈（打印件） 2.0.SLDPRT
02_mechanical/CAD/solidworks/26版sw单件/大腿新改件.SLDPRT
02_mechanical/CAD/solidworks/26版sw单件/大腿新改件二.SLDPRT
02_mechanical/CAD/solidworks/26版sw单件/大腿新间件.SLDPRT
02_mechanical/CAD/solidworks/26版sw单件/工支撑件 2.0.SLDPRT
02_mechanical/CAD/solidworks/26版sw单件/带轮挡板2mm.SLDPRT
02_mechanical/CAD/solidworks/26版sw单件/带轮挡板加厚.SLDPRT
02_mechanical/CAD/solidworks/26版sw单件/电机转接改件钛合金版本.SLDPRT
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

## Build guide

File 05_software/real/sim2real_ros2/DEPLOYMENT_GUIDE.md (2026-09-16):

# ROS 2/C++ Sim2Real 初版部署指南

本工作区保存 `v0.10.0` 的 ROS 2 Humble/C++ 初版。控制栈主体源码已归档，但 Odin 驱动源码在该快照中缺失，因此不是自包含部署包；完成真实传感器闭环前必须补充兼容驱动。

---

## 1. 前提条件与环境

### 硬件
* **目标计算机**：运行 Ubuntu 22.04 LTS 的 Jetson Orin Nano / Orin NX / AGX Orin。
* **IMU 传感器**：Odin 集成 IMU，发布至 `/odin1/imu`。
* **CAN 总线适配器**：Peak CAN、USB-to-CAN 或板载 SocketCAN 接口，使用 CAN0 和 CAN1。

### 主机依赖
* **操作系统**：Ubuntu 22.04 LTS (Jammy Jellyfish)。
* **ROS 2 发行版**：ROS 2 Humble（Desktop-Base 或 ROS-Base）。
* **C++ 编译器**：支持 C++17 的 GCC/G++ 9.0+。
* **库与 ROS2 包**：
  * `libyaml-cpp-dev`
  * `libeigen3-dev`
  * `libusb-1.0-0-dev`（Odin USB 传感器通信）
  * `libpcl-dev` 和 `libopencv-dev`（3D 点云与相机处理）
  * `ros-humble-navigation2` 和 `ros-humble-nav2-bringup`（Nav2 规划器/控制器服务器）
  * `ros-humble-pointcloud-to-laserscan`（点云转激光扫描，供 AMCL 使用）
  * `ros-humble-cv-bridge` 和 `ros-humble-pcl-conversions`（Odin 传感器驱动图像与点云处理）
  * `can-utils`（SocketCAN 验证工具）

---

## 2. 本地编译与部署

按以下步骤在主机系统上编译运行整个栈：

### 步骤 1：安装系统依赖
```bash
sudo apt-get update
sudo apt-get install -y build-essential cmake can-utils libyaml-cpp-dev libeigen3-dev \
    libusb-1.0-0-dev libpcl-dev libopencv-dev ros-humble-navigation2 \
    ros-humble-nav2-bringup ros-humble-pointcloud-to-laserscan \
    ros-humble-cv-bridge ros-humble-pcl-conversions
```

### 步骤 2：下载 ONNXRuntime C++ SDK
策略需要 ONNXRuntime 库来运行推理。必须下载并解压到已知目录：

```bash
# 创建目录
sudo mkdir -p /opt/onnxruntime
cd /opt

# 针对 Jetson Orin (ARM64 / aarch64)：
sudo wget https://github.com/microsoft/onnxruntime/releases/download/v1.16.3/onnxruntime-linux-aarch64-1.16.3.tgz
sudo tar -zxvf onnxruntime-linux-aarch64-1.16.3.tgz --strip-components=1 -C /opt/onnxruntime

# 或标准桌面仿真 (x86_64 / amd64)：
# sudo wget https://github.com/microsoft/onnxruntime/releases/download/v1.16.3/onnxruntime-linux-x64-1.16.3.tgz
# sudo tar -zxvf onnxruntime-linux-x64-1.16.3.tgz --strip-components=1 -C /opt/onnxruntime
```

导出 CMake 辅助变量：
```bash
export ONNXRUNTIME_DIR=/opt/onnxruntime
```

### 步骤 3：构建工作区
进入包含 `src/` 的本包根目录，运行 `colcon`：
```bash
colcon build --merge-install --cmake-args -DCMAKE_BUILD_TYPE=Release
```

### 步骤 4：配置 SocketCAN 接口
启动前，以 1 Mbps 波特率激活 CAN 接口：
```bash
sudo ip link set can0 up type can bitrate 1000000
sudo ip link set can1 up type can bitrate 1000000
```
使用 `ifconfig` 或 `ip link` 验证接口已启动。

### 步骤 5：启动节点
使启动脚本可执行并运行：
```bash
chmod +x start_sim2real.sh
./start_sim2real.sh
```

---

## 3. Docker 部署（推荐）

强烈推荐使用 Docker 隔离依赖，避免 Jetson Orin 上的库版本冲突。

### 步骤 1：构建镜像
确保在 `sim2real_ros2` 目录中（包含 `Dockerfile`）：
```bash
# 使用标准 docker build：
docker build -t sim2real_ros2:latest .

# 或使用 Docker Compose：
docker compose build
```

### 步骤 2：运行容器
对于真实硬件部署，容器**必须**共享主机网络栈（用于 ROS2 DDS 和 SocketCAN）并具备线程优先级能力以实现实时调度：

```bash
# 选项 A：手动运行
docker run -it \
  --network host \
  --privileged \
  --cap-add=sys_nice \
  --volume=/dev:/dev \
  --shm-size=2g \
  --name sim2real_ros2_run \
  sim2real_ros2:latest

# 选项 B：通过 Docker Compose 运行（最简单）
docker compose up -d
```

---

## 4. 系统拓扑与话题

控制节点通过标准 ROS 2 DDS 消息与传感器驱动和导航栈交互：

* **IMU 输入**：订阅 `/odin1/imu`（`sensor_msgs/msg/Imu`）。硬件节点自动执行逆轴旋转（`x_raw = -y_ros`，`y_raw = x_ros`）以重建 RL 策略期望的原始坐标系。
* **控制命令**：订阅 `/cmd_vel` 和 `/cmd_vel_stamped`（`geometry_msgs/msg/Twist` / `TwistStamped`），由导航栈或手动键盘节点发布。
* **里程计输入**：订阅 `/odom`（`nav_msgs/msg/Odometry`），由 `odom_relay_node` 从 `/odin1/odometry` 中继并重映射帧名后提供。
* **急停**：订阅 `/safety/estop`（`std_msgs/msg/Bool`）。发布 `true` 触发软件急停，机器人进入低刚度阻尼刹车。
* **状态遥测**：发布 `runtime/state`（`sim2real_interfaces/msg/RuntimeState`），包含当前关节速度、温度、IMU 输出和诊断信息。
* **策略目标**：发布 `runtime/target`（`sim2real_interfaces/msg/RuntimeTarget`），包含策略推理输出的目标关节位置。

### TF 树
```
odom ──→ base_link    （由 odom_relay_node 广播）
map  ──→ odom         （由 AMCL / Odin SLAM 发布，取决于运行模式）
```

---

## 5. 集成 ROS 2 导航与传感器驱动

### USB 设备权限（Odin 传感器）
要运行物理 Odin 传感器驱动（`odin_ros_driver`），目标计算机必须具有传感器 USB 接口的读写权限。在主机系统上添加以下 udev 规则：

```bash
# 1. 添加 udev 规则
echo 'SUBSYSTEM=="usb", ATTR{idVendor}=="2207", ATTR{idProduct}=="0019", MODE="0666", GROUP="plugdev"' | sudo tee /etc/udev/rules.d/99-odin-usb.rules

# 2. 重新加载 udev 规则并重新插拔传感器
sudo udevadm control --reload
sudo udevadm trigger
```

### 集成启动参数
统一启动文件 `sim2real_system.launch.py` 支持模块化激活传感器驱动和 Nav2 导航栈：

* `launch_driver`（默认：`true`）：启动 `odin_ros_driver` 节点以获取 IMU 和点云遥测。
* `launch_nav2`（默认：`true`）：启动 ROS2 Navigation2 规划器、控制器、costmap、AMCL 和 pointcloud_to_laserscan。

#### 1. 完整真实硬件闭环（默认）
启动运动控制运行时、物理 CAN 桥接、Odin 传感器驱动和 Nav2 导航：
```bash
ros2 launch sim2real_bringup sim2real_system.launch.py dry_run:=false launch_driver:=true launch_nav2:=true
```

#### 2. Dry-Run / 仿真航点测试
在 dry-run 模式下运行策略运行时和 Nav2 导航（不访问 CAN 总线或物理 USB 传感器，适合测试导航话题路由）：
```bash
ros2 launch sim2real_bringup sim2real_system.launch.py dry_run:=true launch_driver:=false launch_nav2:=true
```

#### 3. 仅运动控制（无导航）
禁用传感器驱动和 Nav2，让运动策略等待 `/cmd_vel` 上的手动速度输入（如键盘遥操作）：
```bash
ros2 launch sim2real_bringup sim2real_system.launch.py launch_driver:=false launch_nav2:=false
```

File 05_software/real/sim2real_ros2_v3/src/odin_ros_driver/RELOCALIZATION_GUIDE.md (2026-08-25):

# Relocalization Guide / 重定位使用指南

This guide explains how to use the relocalization feature in Odin ROS Driver, including automatic relocalization and init position relocalization modes.

本指南介绍如何使用 Odin ROS Driver 的重定位功能，包括自动重定位和指定初始位置重定位两种模式。

---

## Table of Contents / 目录

1. [Overview / 概述](#overview--概述)
2. [Prerequisites / 前提条件](#prerequisites--前提条件)
3. [Mode 1: Auto Relocalization / 自动重定位](#mode-1-auto-relocalization--自动重定位)
4. [Mode 2: Init Position Relocalization / 指定初始位置重定位](#mode-2-init-position-relocalization--指定初始位置重定位)
5. [init_pos Format / init_pos 格式说明](#init_pos-format--init_pos-格式说明)
6. [Configuration Examples / 配置示例](#configuration-examples--配置示例)
7. [Programmatic API / 编程接口](#programmatic-api--编程接口)
8. [Troubleshooting / 故障排除](#troubleshooting--故障排除)

---

## Overview / 概述

### English

Relocalization mode (`custom_map_mode: 2`) allows Odin to localize itself within a pre-built map. There are two approaches:

| Mode | Description | Use Case |
|---|---|---|
| **Auto Relocalization** | Algorithm automatically searches for position in the map | Starting position is unknown or within recommended range |
| **Init Position Relocalization** | User provides an initial pose estimate via `init_pos` | Starting position is known, faster convergence needed |

### 中文

重定位模式（`custom_map_mode: 2`）允许 Odin 在预先构建的地图中进行自我定位。有两种方式：

| 模式 | 描述 | 适用场景 |
|---|---|---|
| **自动重定位** | 算法自动在地图中搜索位置 | 起始位置未知，或在推荐范围内 |
| **指定初始位置重定位** | 用户通过 `init_pos` 提供初始位姿估计 | 起始位置已知，需要更快收敛 |

---

## Prerequisites / 前提条件

### English

1. **Pre-built map file**: A `.bin` map file created in SLAM mode (`custom_map_mode: 1`)
2. **Map file path**: Know the absolute path to your map file
3. **Starting position**: For init position mode, know the approximate starting pose in map coordinates

### 中文

1. **预构建的地图文件**：在 SLAM 模式（`custom_map_mode: 1`）下创建的 `.bin` 地图文件
2. **地图文件路径**：知道地图文件的绝对路径
3. **起始位置**：对于指定初始位置模式，需要知道在地图坐标系中的大致起始位姿

---

## Mode 1: Auto Relocalization / 自动重定位

### English

In auto relocalization mode, the algorithm automatically searches for the device's position within the map based on current sensor observations.

**Configuration** (`config/control_command.yaml`):

```yaml
register_keys:
  custom_map_mode: 2
  relocalization_map_abs_path: "/path/to/your/map.bin"
  # custom_init_pos is NOT set or uses default [0,0,0,0,0,0,1]
```

**Recommended Starting Conditions**:
- Within **1 meter** of a position on the original SLAM trajectory
- Within **±10 degrees** of the original orientation
- In a visually distinctive area of the map

**Behavior**:
1. On startup, Odin attempts to match current observations with the map
2. If successful, TF between `map` and `odom` frames is published
3. If unsuccessful, system operates in fallback SLAM mode (map saving disabled)
4. Relocalization attempts continue in background until successful

**Tips**:
- Gently shaking or moving the device after startup can improve relocalization accuracy
- Highly distinctive scenes may allow successful matching beyond the 1m/10° range

### 中文

在自动重定位模式下，算法根据当前传感器观测自动在地图中搜索设备位置。

**配置** (`config/control_command.yaml`):

```yaml
register_keys:
  custom_map_mode: 2
  relocalization_map_abs_path: "/path/to/your/map.bin"
  # custom_init_pos 不设置或使用默认值 [0,0,0,0,0,0,1]
```

**推荐起始条件**：
- 距离原始 SLAM 轨迹上某点 **1 米**以内
- 朝向与原始方向偏差在 **±10 度**以内
- 位于地图中视觉特征明显的区域

**行为**：
1. 启动时，Odin 尝试将当前观测与地图匹配
2. 如果成功，发布 `map` 和 `odom` 坐标系之间的 TF
3. 如果失败，系统进入后备 SLAM 模式（地图保存功能禁用）
4. 后台持续尝试重定位直到成功

**提示**：
- 启动后轻轻晃动或移动设备可以提高重定位精度
- 在特征明显的场景中，可能在超出 1m/10° 范围时也能成功匹配

---

## Mode 2: Init Position Relocalization / 指定初始位置重定位

### English

In init position relocalization mode, you provide an initial pose estimate to help the algorithm converge faster.

**Configuration** (`config/control_command.yaml`):

```yaml
register_keys:
  custom_map_mode: 2
  relocalization_map_abs_path: "/path/to/your/map.bin"
  custom_init_pos: [x, y, z, qx, qy, qz, qw]
```

**When to Use**:
- You know the approximate starting position (e.g., from external localization system)
- Starting position is far from the recommended 1m/10° range
- You need faster relocalization convergence
- Deploying in a fixed docking station with known pose

**Behavior**:
1. Algorithm uses provided `init_pos` as initial pose estimate
2. Searches for matches in the vicinity of the provided position
3. Faster convergence compared to auto mode when estimate is accurate

### 中文

在指定初始位置重定位模式下，您提供初始位姿估计以帮助算法更快收敛。

**配置** (`config/control_command.yaml`):

```yaml
register_keys:
  custom_map_mode: 2
  relocalization_map_abs_path: "/path/to/your/map.bin"
  custom_init_pos: [x, y, z, qx, qy, qz, qw]
```

**适用场景**：
- 您知道大致的起始位置（例如，来自外部定位系统）
- 起始位置远离推荐的 1m/10° 范围
- 需要更快的重定位收敛速度
- 部署在已知位姿的固定充电桩

**行为**：
1. 算法使用提供的 `init_pos` 作为初始位姿估计
2. 在提供位置的附近搜索匹配
3. 当估计准确时，比自动模式收敛更快

---

## init_pos Format / init_pos 格式说明

### English

`init_pos` is an array of **7 float values** representing position and orientation:

```yaml
custom_init_pos: [x, y, z, qx, qy, qz, qw]
```

| Index | Parameter | Description | Unit |
|---|---|---|---|
| 0 | x | X position in map frame | meters |
| 1 | y | Y position in map frame | meters |
| 2 | z | Z position in map frame | meters |
| 3 | qx | Quaternion X component | - |
| 4 | qy | Quaternion Y component | - |
| 5 | qz | Quaternion Z component | - |
| 6 | qw | Quaternion W component | - |

**Important Notes**:
- The quaternion must be normalized: `sqrt(qx² + qy² + qz² + qw²) ≈ 1.0`
- Coordinates are relative to the **map frame** (world frame at SLAM start)
- Default value `[0, 0, 0, 0, 0, 0, 1]` represents origin with no rotation

**Common Quaternion Values**:

| Orientation | qx | qy | qz | qw |
|---|----|----|----|----|
| No rotation (identity) | 0 | 0 | 0 | 1 |
| 90° around Z-axis | 0 | 0 | 0.707 | 0.707 |
| 180° around Z-axis | 0 | 0 | 1 | 0 |
| -90° around Z-axis | 0 | 0 | -0.707 | 0.707 |

### 中文

`init_pos` 是一个包含 **7 个 float 值**的数组，表示位置和朝向：

```yaml
custom_init_pos: [x, y, z, qx, qy, qz, qw]
```

| 索引 | 参数 | 描述 | 单位 |
|---|---|---|---|
| 0 | x | 地图坐标系中的 X 位置 | 米 |
| 1 | y | 地图坐标系中的 Y 位置 | 米 |
| 2 | z | 地图坐标系中的 Z 位置 | 米 |
| 3 | qx | 四元数 X 分量 | - |
| 4 | qy | 四元数 Y 分量 | - |
| 5 | qz | 四元数 Z 分量 | - |
| 6 | qw | 四元数 W 分量 | - |

**重要说明**：
- 四元数必须归一化：`sqrt(qx² + qy² + qz² + qw²) ≈ 1.0`
- 坐标相对于**地图坐标系**（SLAM 启动时的世界坐标系）
- 默认值 `[0, 0, 0, 0, 0, 0, 1]` 表示原点且无旋转

**常用四元数值**：

| 朝向 | qx | qy | qz | qw |
|---|----|----|----|----|
| 无旋转（单位四元数） | 0 | 0 | 0 | 1 |
| 绕 Z 轴旋转 90° | 0 | 0 | 0.707 | 0.707 |
| 绕 Z 轴旋转 180° | 0 | 0 | 1 | 0 |
| 绕 Z 轴旋转 -90° | 0 | 0 | -0.707 | 0.707 |

---

## Configuration Examples / 配置示例

### Example 1: Auto Relocalization / 自动重定位示例

```yaml
register_keys:
  custom_map_mode: 2
  relocalization_map_abs_path: "/home/user/maps/office_map.bin"
```

### Example 2: Init Position at Origin / 在原点指定初始位置

```yaml
register_keys:
  custom_map_mode: 2
  relocalization_map_abs_path: "/home/user/maps/office_map.bin"
  custom_init_pos: [0.0, 0.0, 0.0, 0.0, 0.0, 0.0, 1.0]
```

### Example 3: Init Position with Offset / 带偏移的初始位置

Position at (5.2, -3.1, 0) with 90° rotation around Z-axis:

位置在 (5.2, -3.1, 0)，绕 Z 轴旋转 90°：

```yaml
register_keys:
  custom_map_mode: 2
  relocalization_map_abs_path: "/home/user/maps/warehouse_map.bin"
  custom_init_pos: [5.2, -3.1, 0.0, 0.0, 0.0, 0.707, 0.707]
```

### Example 4: Docking Station Pose / 充电桩位置

Known docking station at (10.5, 2.3, 0) facing -X direction (180° rotation):

已知充电桩位置在 (10.5, 2.3, 0)，朝向 -X 方向（旋转 180°）：

```yaml
register_keys:
  custom_map_mode: 2
  relocalization_map_abs_path: "/home/user/maps/factory_map.bin"
  custom_init_pos: [10.5, 2.3, 0.0, 0.0, 0.0, 1.0, 0.0]
```

---

## Programmatic API / 编程接口

### English

You can also set `init_pos` programmatically using the `lidar_set_custom_parameter` API. This is useful for:
- Dynamic relocalization during runtime
- Integration with external localization systems
- Setting initial pose from robot's last known position

#### API Function

```cpp
#include "lidar_api.h"

/**
 * @brief Set a custom parameter on the device
 * @param device      Device handle obtained from lidar_open_device()
 * @param param_name  Parameter name (e.g., "init_pos")
 * @param value_data  Pointer to the parameter data
 * @param value_length Size of the data in bytes
 * @return 0 on success, -1 on error, -2 if file transfer in progress
 */
int lidar_set_custom_parameter(device_handle device, 
                                const char* param_name, 
                                const void* value_data, 
                                size_t value_length);
```

#### Complete Example

```cpp
#include "lidar_api.h"
#include <cstdio>
#include <cmath>

// Helper function to create quaternion from yaw angle (rotation around Z-axis)
void yaw_to_quaternion(float yaw_rad, float* qx, float* qy, float* qz, float* qw) {
    *qx = 0.0f;
    *qy = 0.0f;
    *qz = sinf(yaw_rad / 2.0f);
    *qw = cosf(yaw_rad / 2.0f);
}

int set_init_position(device_handle device, 
                      float x, float y, float z, 
                      float qx, float qy, float qz, float qw) {
    // init_pos format: [x, y, z, qx, qy, qz, qw] - 7 floats
    float init_pos[7] = {x, y, z, qx, qy, qz, qw};
    
    int result = lidar_set_custom_parameter(
        device,
        "init_pos",           // Parameter name
        init_pos,             // Data pointer
        sizeof(init_pos)      // 7 * sizeof(float) = 28 bytes
    );
    
    if (result == 0) {
        printf("Successfully set init_pos: [%.3f, %.3f, %.3f, %.3f, %.3f, %.3f, %.3f]\n",
               x, y, z, qx, qy, qz, qw);
    } else {
        printf("Failed to set init_pos, error code: %d\n", result);
    }
    
    return result;
}

// Usage examples:

// Example 1: Set position at origin with no rotation
void example_origin(device_handle device) {
    set_init_position(device, 
                      0.0f, 0.0f, 0.0f,      // x, y, z
                      0.0f, 0.0f, 0.0f, 1.0f // qx, qy, qz, qw (identity)
    );
}

// Example 2: Set position with 90° yaw rotation
void example_with_rotation(device_handle device) {
    float qx, qy, qz, qw;
    float yaw_degrees = 90.0f;
    float yaw_rad = yaw_degrees * M_PI / 180.0f;
    
    yaw_to_quaternion(yaw_rad, &qx, &qy, &qz, &qw);
    
    set_init_position(device,
                      5.2f, -3.1f, 0.0f,    // x, y, z
                      qx, qy, qz, qw        // quaternion from yaw
    );
}

// Example 3: Set position from external localization system
void example_from_external_localization(device_handle device,
                                         double ext_x, double ext_y, double ext_yaw) {
    float qx, qy, qz, qw;
    yaw_to_quaternion((float)ext_yaw, &qx, &qy, &qz, &qw);
    
    set_init_position(device,
                      (float)ext_x, (float)ext_y, 0.0f,
                      qx, qy, qz, qw
    );
}
```

#### ROS Integration Example

```cpp
#include "lidar_api.h"
#include <geometry_msgs/PoseWithCovarianceStamped.h>  // ROS1
// or
#include <geometry_msgs/msg/pose_with_covariance_stamped.hpp>  // ROS2

// Callback for /initialpose topic (from RViz "2D Pose Estimate" tool)
void initialPoseCallback(const geometry_msgs::PoseWithCovarianceStamped::ConstPtr& msg,
                         device_handle device) {
    float init_pos[7] = {
        (float)msg->pose.pose.position.x,
        (float)msg->pose.pose.position.y,
        (float)msg->pose.pose.position.z,
        (float)msg->pose.pose.orientation.x,
        (float)msg->pose.pose.orientation.y,
        (float)msg->pose.pose.orientation.z,
        (float)msg->pose.pose.orientation.w
    };
    
    int result = lidar_set_custom_parameter(device, "init_pos", init_pos, sizeof(init_pos));
    
    if (result == 0) {
        ROS_INFO("Set init_pos from RViz: [%.2f, %.2f, %.2f]", 
                 init_pos[0], init_pos[1], init_pos[2]);
    } else {
        ROS_ERROR("Failed to set init_pos: %d", result);
    }
}
```

#### Important Notes

1. **Call timing**: Set `init_pos` **before** starting the stream with `lidar_start_stream()`
2. **Map mode**: Ensure `custom_map_mode` is set to `2` (relocalization mode)
3. **Map file**: The relocalization map must be set via `lidar_set_relocalization_map()` or YAML config
4. **Thread safety**: `lidar_set_custom_parameter` is thread-safe but blocks until response received

### 中文

您也可以使用 `lidar_set_custom_parameter` API 以编程方式设置 `init_pos`。适用于：
- 运行时动态重定位
- 与外部定位系统集成
- 从机器人上次已知位置设置初始位姿

#### API 函数

```cpp
#include "lidar_api.h"

/**
 * @brief 在设备上设置自定义参数
 * @param device      从 lidar_open_device() 获取的设备句柄
 * @param param_name  参数名称（如 "init_pos"）
 * @param value_data  指向参数数据的指针
 * @param value_length 数据大小（字节）
 * @return 成功返回 0，错误返回 -1，文件传输中返回 -2
 */
int lidar_set_custom_parameter(device_handle device, 
                                const char* param_name, 
                                const void* value_data, 
                                size_t value_length);
```

#### 完整示例

```cpp
#include "lidar_api.h"
#include <cstdio>
#include <cmath>

// 辅助函数：从偏航角（绕 Z 轴旋转）创建四元数
void yaw_to_quaternion(float yaw_rad, float* qx, float* qy, float* qz, float* qw) {
    *qx = 0.0f;
    *qy = 0.0f;
    *qz = sinf(yaw_rad / 2.0f);
    *qw = cosf(yaw_rad / 2.0f);
}

int set_init_position(device_handle device, 
                      float x, float y, float z, 
                      float qx, float qy, float qz, float qw) {
    // init_pos 格式: [x, y, z, qx, qy, qz, qw] - 7 个 float
    float init_pos[7] = {x, y, z, qx, qy, qz, qw};
    
    int result = lidar_set_custom_parameter(
        device,
        "init_pos",           // 参数名
        init_pos,             // 数据指针
        sizeof(init_pos)      // 7 * sizeof(float) = 28 字节
    );
    
    if (result == 0) {
        printf("成功设置 init_pos: [%.3f, %.3f, %.3f, %.3f, %.3f, %.3f, %.3f]\n",
               x, y, z, qx, qy, qz, qw);
    } else {
        printf("设置 init_pos 失败，错误码: %d\n", result);
    }
    
    return result;
}

// 使用示例：

// 示例 1：在原点设置位置，无旋转
void example_origin(device_handle device) {
    set_init_position(device, 
                      0.0f, 0.0f, 0.0f,      // x, y, z
                      0.0f, 0.0f, 0.0f, 1.0f // qx, qy, qz, qw（单位四元数）
    );
}

// 示例 2：设置带 90° 偏航旋转的位置
void example_with_rotation(device_handle device) {
    float qx, qy, qz, qw;
    float yaw_degrees = 90.0f;
    float yaw_rad = yaw_degrees * M_PI / 180.0f;
    
    yaw_to_quaternion(yaw_rad, &qx, &qy, &qz, &qw);
    
    set_init_position(device,
                      5.2f, -3.1f, 0.0f,    // x, y, z
                      qx, qy, qz, qw        // 从偏航角计算的四元数
    );
}

// 示例 3：从外部定位系统设置位置
void example_from_external_localization(device_handle device,
                                         double ext_x, double ext_y, double ext_yaw) {
    float qx, qy, qz, qw;
    yaw_to_quaternion((float)ext_yaw, &qx, &qy, &qz, &qw);
    
    set_init_position(device,
                      (float)ext_x, (float)ext_y, 0.0f,
                      qx, qy, qz, qw
    );
}
```

#### ROS 集成示例

```cpp
#include "lidar_api.h"
#include <geometry_msgs/PoseWithCovarianceStamped.h>  // ROS1
// 或
#include <geometry_msgs/msg/pose_with_covariance_stamped.hpp>  // ROS2

// /initialpose 话题的回调函数（来自 RViz 的 "2D Pose Estimate" 工具）
void initialPoseCallback(const geometry_msgs::PoseWithCovarianceStamped::ConstPtr& msg,
                         device_handle device) {
    float init_pos[7] = {
        (float)msg->pose.pose.position.x,
        (float)msg->pose.pose.position.y,
        (float)msg->pose.pose.position.z,
        (float)msg->pose.pose.orientation.x,
        (float)msg->pose.pose.orientation.y,
        (float)msg->pose.pose.orientation.z,
        (float)msg->pose.pose.orientation.w
    };
    
    int result = lidar_set_custom_parameter(device, "init_pos", init_pos, sizeof(init_pos));
    
    if (result == 0) {
        ROS_INFO("从 RViz 设置 init_pos: [%.2f, %.2f, %.2f]", 
                 init_pos[0], init_pos[1], init_pos[2]);
    } else {
        ROS_ERROR("设置 init_pos 失败: %d", result);
    }
}
```

#### 重要说明

1. **调用时机**：在调用 `lidar_start_stream()` 启动数据流**之前**设置 `init_pos`
2. **地图模式**：确保 `custom_map_mode` 设置为 `2`（重定位模式）
3. **地图文件**：必须通过 `lidar_set_relocalization_map()` 或 YAML 配置设置重定位地图
4. **线程安全**：`lidar_set_custom_parameter` 是线程安全的，但会阻塞直到收到响应

---

## Troubleshooting / 故障排除

### Relocalization Fails / 重定位失败

**English**:
- Ensure starting position is within recommended range (1m/10°)
- Check that the map file path is correct and file exists
- Verify the environment hasn't changed significantly since mapping
- Try gently moving the device to provide more observations

**中文**：
- 确保起始位置在推荐范围内（1m/10°）
- 检查地图文件路径是否正确且文件存在
- 验证环境自建图以来没有显著变化
- 尝试轻轻移动设备以提供更多观测

### init_pos Not Taking Effect / init_pos 未生效

**English**:
- Verify `custom_map_mode` is set to `2`
- Check that `custom_init_pos` has exactly 7 values
- Ensure quaternion is normalized (sum of squares ≈ 1)
- Restart the driver after modifying configuration

**中文**：
- 验证 `custom_map_mode` 设置为 `2`
- 检查 `custom_init_pos` 是否恰好有 7 个值
- 确保四元数已归一化（平方和 ≈ 1）
- 修改配置后重启驱动程序

### TF Not Published / TF 未发布

**English**:
- Relocalization may still be in progress
- Check ROS logs for relocalization status messages
- System operates in fallback mode until relocalization succeeds

**中文**：
- 重定位可能仍在进行中
- 检查 ROS 日志中的重定位状态消息
- 系统在重定位成功前以后备模式运行

### Map File Not Found / 地图文件未找到

**English**:
- Use absolute path (starting with `/`)
- Check file permissions
- Verify file extension is `.bin`

**中文**：
- 使用绝对路径（以 `/` 开头）
- 检查文件权限
- 验证文件扩展名为 `.bin`

---

## Related Topics / 相关话题

| Topic | Description |
|---|---|
| `/odin1/odometry` | Odometry in odom frame |
| `/odin1/odometry_highfreq` | High-frequency odometry |
| `/odin1/cloud_slam` | SLAM point cloud in odom frame |
| `/tf` | Transform tree (includes map→odom after successful relocalization) |

---

## See Also / 参见

- [README.md](README.md) - Main documentation
- [config/control_command.yaml](config/control_command.yaml) - Configuration file

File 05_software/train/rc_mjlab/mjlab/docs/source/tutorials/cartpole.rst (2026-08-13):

.. _tutorial-cartpole:

Cartpole: Building Your First Environment
=========================================

This tutorial walks through building a cartpole swingup task from scratch.
A cart slides along a rail with a pole attached by a hinge. The agent
applies force to the cart to swing the pole up and balance it.

.. raw:: html

   <video style="width:80%; display:block; margin:0 auto;" autoplay loop muted playsinline>
     <source src="../../_static/tutorials/cartpole_swingup.mp4" type="video/mp4">
   </video>
   <p style="text-align:center; color:#666; font-size:0.9em; margin-top:0.5em;">
     A trained agent performing the swingup task.
   </p>

The entire task lives in two files: an XML model and a Python module. We
will build both piece by piece, then snap them together at the end.

The XML model
-------------

Every environment starts with a MuJoCo XML that defines the physical
system. For cartpole that means two bodies, two joints, and one motor:

.. code-block:: xml

    <!-- A cart on a rail with a pole attached by a hinge. -->
    <body name="cart" pos="0 0 1">
      <joint name="slider" type="slide" axis="1 0 0"
             limited="true" range="-1.8 1.8" damping="5e-4"/>
      <geom name="cart" type="box" size="0.2 0.15 0.1" mass="1"/>
      <body name="pole_1" childclass="pole">
        <joint name="hinge_1"/>
        <geom name="pole_1"/>
      </body>
    </body>

    <!-- A motor that pushes the cart along the rail. -->
    <actuator>
      <motor name="slide" joint="slider" gear="10"
             ctrllimited="true" ctrlrange="-1 1"/>
    </actuator>

The motor has gear ratio 10 and control range [-1, 1], so the maximum
force is 10 N. ``ctrllimited`` tells MuJoCo to clamp the control signal
internally, so policy outputs outside this range are safe.

The full XML is at ``src/mjlab/tasks/cartpole/cartpole.xml``.

Building the environment
------------------------

Everything else lives in a single file, ``cartpole_env_cfg.py``. An
mjlab environment is made of small, composable pieces. We will define
each piece, then assemble them into a complete config at the end.

Entity: wrapping the XML
^^^^^^^^^^^^^^^^^^^^^^^^

An entity is a simulated object in the scene. It can be anything from a
static table to an articulated robot. The ``EntityCfg`` wraps a MuJoCo
XML and, optionally, actuator and initial state configurations. At
runtime, the entity exposes simulation data (joint positions, velocities,
etc.) as batched PyTorch tensors.

The cartpole is an articulated entity with one actuator, so we need a
function that loads the XML, an actuator configuration, and an initial
state.

.. code-block:: python

    # Load the XML.
    _CARTPOLE_XML = Path(__file__).parent / "cartpole.xml"

    def _get_spec() -> mujoco.MjSpec:
        return mujoco.MjSpec.from_file(str(_CARTPOLE_XML))

    # Tell mjlab to use the motor defined in the XML as is.
    _CARTPOLE_ARTICULATION = EntityArticulationInfoCfg(
        actuators=(XmlActuatorCfg(target_names_expr=("slider",)),),
    )

The initial joint state depends on the task variant:

.. tab-set::

   .. tab-item:: Swingup

      The pole starts pointing down (``hinge = pi``). The agent must swing
      it up and balance it.

      .. code-block:: python

          _SWINGUP_INIT = EntityCfg.InitialStateCfg(
              joint_pos={"slider": 0.0, "hinge_1": math.pi},
              joint_vel={".*": 0.0},
          )

   .. tab-item:: Balance

      The pole starts upright (``hinge = 0``). The agent only needs to
      keep it balanced.

      .. code-block:: python

          _BALANCE_INIT = EntityCfg.InitialStateCfg(
              joint_pos={"slider": 0.0, "hinge_1": 0.0},
              joint_vel={".*": 0.0},
          )

Now we can snap these together into an ``EntityCfg``:

.. code-block:: python

    # Bundle the spec loader, actuator, and initial state into one config.
    def _get_cartpole_cfg(swing_up: bool = False) -> EntityCfg:
        return EntityCfg(
            spec_fn=_get_spec,
            articulation=_CARTPOLE_ARTICULATION,
            init_state=_SWINGUP_INIT if swing_up else _BALANCE_INIT,
        )

That is the entity done. Later, we will pass it to the scene so the
environment knows what to simulate.

Observations: what the agent sees
^^^^^^^^^^^^^^^^^^^^^^^^^^^^^^^^^

Each observation term is a function that reads from the simulation and
returns a tensor. The observation manager concatenates them into a single
vector for the policy. mjlab provides common terms in ``mjlab.envs.mdp``
(joint positions, velocities, etc.), but you can always define your own.

The cartpole has two moving parts, so its physical state is fully
described by two positions and two velocities:

.. list-table::
   :header-rows: 1
   :widths: 22 12 66

   * - Term
     - Dim
     - Description
   * - ``cart_pos``
     - 1
     - Where is the cart on the rail?
   * - ``pole_angle``
     - 2
     - Which way is the pole pointing? (cosine and sine)
   * - ``cart_vel``
     - 1
     - How fast is the cart moving?
   * - ``pole_vel``
     - 1
     - How fast is the pole rotating?

.. tip::

   The pole angle is encoded as cosine and sine rather than a raw angle.
   MuJoCo's unlimited hinge does not wrap the angle, so as the pole
   spins the raw value keeps growing. Cosine and sine give the same
   output for the same physical angle regardless of how many rotations
   have occurred.

This is the one custom observation function:

.. code-block:: python

    def pole_angle_cos_sin(env, asset_cfg) -> torch.Tensor:
        asset: Entity = env.scene[asset_cfg.name]
        angle = asset.data.joint_pos[:, asset_cfg.joint_ids]
        return torch.cat([torch.cos(angle), torch.sin(angle)], dim=-1)

.. note::

   All data in mjlab is batched: tensors have shape
   ``[num_envs, ...]`` because many environments run in parallel.
   Every function you write should accept and return tensors with this
   leading batch dimension.

To wire these up, we create ``ObservationTermCfg`` entries and group
them. ``SceneEntityCfg`` scopes each function to specific joints on
the entity:

.. code-block:: python

    cart_cfg = SceneEntityCfg("cartpole", joint_names=("slider",))
    hinge_cfg = SceneEntityCfg("cartpole", joint_names=("hinge_1",))

    cart_pos = ObservationTermCfg(
        func=joint_pos_rel, params={"asset_cfg": cart_cfg},
    )
    pole_angle = ObservationTermCfg(
        func=pole_angle_cos_sin, params={"asset_cfg": hinge_cfg},
    )
    cart_vel = ObservationTermCfg(
        func=joint_vel_rel, params={"asset_cfg": cart_cfg},
    )
    pole_vel = ObservationTermCfg(
        func=joint_vel_rel, params={"asset_cfg": hinge_cfg},
    )

Each term pairs a function with the parameters to call it with. Now
we group them. The RL algorithm expects an ``"actor"`` and ``"critic"``
group; they share the same terms here, but when you add noise later
you can give the critic clean observations
(asymmetric actor-critic [#aac]_).

.. code-block:: python

    actor_terms = {
        "cart_pos": cart_pos,
        "pole_angle": pole_angle,
        "cart_vel": cart_vel,
        "pole_vel": pole_vel,
    }

    observations = {
        "actor": ObservationGroupCfg(actor_terms),
        "critic": ObservationGroupCfg({**actor_terms}),
    }

Actions: what the agent does
^^^^^^^^^^^^^^^^^^^^^^^^^^^^

The agent outputs a single scalar: the force on the cart.
``JointEffortActionCfg`` writes the policy output to the actuator's
effort target. The ``XmlActuator`` passes it to MuJoCo's ``ctrl``
buffer, which clamps it to [-1, 1] and multiplies by the gear ratio:

.. code-block:: python

    actions = {
        "effort": JointEffortActionCfg(
            entity_name="cartpole",
            actuator_names=("slider",),
            scale=1.0,
        ),
    }

Rewards: the training signal
^^^^^^^^^^^^^^^^^^^^^^^^^^^^

Each reward term is a function that returns a scalar per environment.
The reward manager computes a weighted sum of all terms each step.

The cartpole reward reproduces dm_control's smooth reward as a single
multiplicative term:

.. math::

   r = \underbrace{\frac{\cos\theta + 1}{2}}_{\text{upright}}
       \times \underbrace{\frac{1 + g(x)}{2}}_{\text{centered}}
       \times \underbrace{\frac{4 + q(u)}{5}}_{\text{small control}}
       \times \underbrace{\frac{1 + g(\dot\theta)}{2}}_{\text{small velocity}}

Each factor is between 0 and 1. The product is high only when all four
conditions hold simultaneously, preventing the agent from trading off
one factor against another.

.. code-block:: python

    rewards = {
        "smooth_reward": RewardTermCfg(
            func=cartpole_smooth_reward,
            weight=1.0,
            params={"cart_cfg": cart_cfg, "hinge_cfg": hinge_cfg},
        ),
    }

Terminations: when to stop
^^^^^^^^^^^^^^^^^^^^^^^^^^

The cartpole has no failure states, so the only termination is a time
limit. Setting ``time_out=True`` tells the RL algorithm this is a
truncation, not a true terminal state, so it bootstraps the value
function past the episode boundary:

.. code-block:: python

    terminations = {
        "time_out": TerminationTermCfg(func=time_out, time_out=True),
    }

Events: resetting the state
^^^^^^^^^^^^^^^^^^^^^^^^^^^

At the start of each episode, reset events randomize joint positions and
velocities around the initial state we defined in the entity:

.. code-block:: python

    events = {
        "reset_slider": EventTermCfg(
            func=reset_joints_by_offset,
            mode="reset",
            params={
                "position_range": (-0.1, 0.1),
                "velocity_range": (-0.01, 0.01),
                "asset_cfg": SceneEntityCfg("cartpole", joint_names=("slider",)),
            },
        ),
        "reset_hinge": EventTermCfg(
            func=reset_joints_by_offset,
            mode="reset",
            params={
                "position_range": (-0.034, 0.034),
                "velocity_range": (-0.01, 0.01),
                "asset_cfg": SceneEntityCfg("cartpole", joint_names=("hinge_1",)),
            },
        ),
    }

The offsets are relative to the entity's initial state. For swingup the
hinge starts at pi, so the noise keeps it near pointing down.

Snapping everything together
^^^^^^^^^^^^^^^^^^^^^^^^^^^^

``ManagerBasedRlEnvCfg`` is where all the pieces come together. The
scene holds the entity, and the config holds everything else:

.. code-block:: python

    return ManagerBasedRlEnvCfg(
        scene=SceneCfg(
            terrain=TerrainEntityCfg(terrain_type="plane"),
            entities={"cartpole": _get_cartpole_cfg(swing_up=swing_up)},
            num_envs=1,
            env_spacing=4.0,
        ),
        observations=observations,
        actions=actions,
        events=events,
        rewards=rewards,
        terminations=terminations,
        sim=SimulationCfg(
            mujoco=MujocoCfg(timestep=0.01, disableflags=("contact",)),
        ),
        decimation=5,
        episode_length_s=50.0,
    )

``decimation=5`` means the physics runs five substeps per policy step,
giving a 20 Hz control frequency. ``disableflags=("contact",)`` skips
contact computation since cartpole has no collisions. ``num_envs=1`` is
the default; override it from the CLI with ``--num-envs``.

Registration and training
-------------------------

The last step is to register the task so it can be launched by name.
Each registration pairs an environment config with an RL config that
specifies the network architecture and PPO hyperparameters. For cartpole
a small network of two 64 unit hidden layers is plenty. The full RL
config is in ``cartpole_env_cfg.py`` alongside the environment config.

This goes in ``__init__.py``:

.. code-block:: python

    register_mjlab_task(
        task_id="Mjlab-Cartpole-Swingup",
        env_cfg=cartpole_swingup_env_cfg(),
        play_env_cfg=cartpole_swingup_env_cfg(play=True),
        rl_cfg=cartpole_ppo_runner_cfg(),
    )

Train:

.. code-block:: bash

    uv run train Mjlab-Cartpole-Swingup --env.scene.num-envs 4096

Play back a trained checkpoint, either from a local file or a W&B run:

.. code-block:: bash

    uv run play Mjlab-Cartpole-Swingup --checkpoint-file logs/rsl_rl/cartpole/model_500.pt
    uv run play Mjlab-Cartpole-Swingup --wandb-run-path <user/project/run_id>

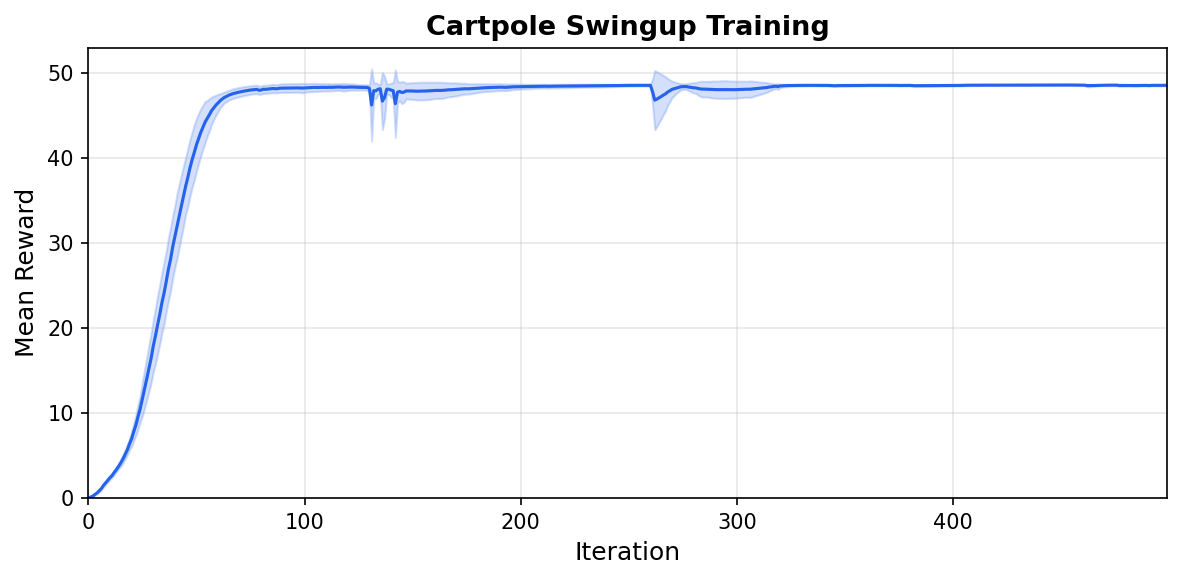
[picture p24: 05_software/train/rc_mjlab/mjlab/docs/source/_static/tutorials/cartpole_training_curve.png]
Cartpole swingup training curve


   Mean reward over 5 seeds (shaded: one standard deviation).

Config fields can be overridden from the CLI:

.. code-block:: bash

    uv run train Mjlab-Cartpole-Swingup \
        --num-envs 8192 \
        --agent.algorithm.learning-rate 3e-4 \
        --agent.algorithm.entropy-coef 0.005

Next steps
----------

**Add observation noise.** The current config has no noise, so the
policy is brittle. Add noise to any observation term to train a more
robust policy:

.. code-block:: python

    from mjlab.utils.noise import UniformNoiseCfg

    ObservationTermCfg(
        func=joint_pos_rel,
        params={"asset_cfg": cart_cfg},
        noise=UniformNoiseCfg(n_min=-0.05, n_max=0.05),
    )

**Randomize the physics.** Use the :ref:`domain_randomization` system
to vary pole mass or joint damping across environments, training a
policy that transfers across physical variations.

**Explore other tasks.** The library ships with locomotion,
manipulation, and motion tracking tasks you can run out of the box:
``Mjlab-Velocity-Flat-Unitree-Go1``, ``Mjlab-Lift-Cube-Yam``, and
``Mjlab-Tracking-Flat-Unitree-G1``, among others. Reading their source
shows how more complex observation and reward structures are composed.

**Build something new.** The cartpole is intentionally minimal. Once
you are comfortable with the pieces, try designing your own robot model
and task from scratch. The same pattern applies regardless of how
complex the system becomes.

.. rubric:: References

.. [#aac] Pinto, L., Andrychowicz, M., Welinder, P., Zaremba, W., & Abbeel, P. (2018). `Asymmetric Actor Critic for Image-Based Robot Learning <https://www.roboticsproceedings.org/rss14/p08.pdf>`_. *Robotics: Science and Systems XIV*.

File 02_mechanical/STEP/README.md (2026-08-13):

# STEP 交换文件

本目录提供不依赖 SolidWorks 的通用机械交换文件。

- `WEEKDOG.STEP`：整机
- `DOG身体.STEP`：机器人身体
- `髋关节END.STEP`：髋关节
- `大腿.STEP`：大腿组件
- `轮小腿.STEP`：轮足小腿组件
- `轮子完整.STEP`：完整轮组
- 其余文件：轮子、轮毂垫片和连接零件

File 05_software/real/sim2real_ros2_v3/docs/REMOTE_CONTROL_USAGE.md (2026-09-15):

# sim2real_ros2_v3 遥控器调用说明

本文档说明如何在 `sim2real_ros2_v3` 中调用已接入的 SBUS UART 遥控器节点，以及执行后系统会产生什么效果。

## 1. 当前接入关系

遥控器节点位于：

```text
src/sim2real_runtime/src/remote_uart_node.py
```

该节点读取 SBUS 串口数据，并发布标准 ROS 2 控制话题：

| 输入 | 输出 | 作用 |
|---|---|---|
| SBUS UART 遥控器 | `/cmd_vel` | 给策略运行时发送速度命令 |
| SBUS CH7 高位 | `/safety/estop` | 触发软件急停 |

策略节点 `sim2real_runtime_node` 已经订阅 `/cmd_vel` 和 `/safety/estop`，所以遥控器不直接控制电机，而是通过 ROS 2 标准速度接口进入策略控制链路。

## 2. 通道映射

通道映射与本仓库第一代 Python Sim2Real 实现中的遥控器配置保持一致。

| 遥控器通道 | ROS 2 输出 | 含义 | 默认最大值 |
|---|---|---|---:|
| `CH2` | `cmd_vel.linear.x` | 前后速度 `vx` | `0.8 m/s` |
| `CH4` | `cmd_vel.linear.y` | 左右速度 `vy` | `0.3 m/s` |
| `CH1` | `cmd_vel.angular.z` | 转向角速度 `yaw` | `0.5 rad/s` |
| `CH7 HIGH` | `/safety/estop = true` | 软件急停 | - |

默认方向反转配置：

| 参数 | 默认值 | 含义 |
|---|---:|---|
| `remote_invert_vx` | `true` | 反转前后方向 |
| `remote_invert_vy` | `false` | 不反转横移方向 |
| `remote_invert_yaw` | `true` | 反转转向方向 |

## 3. 参数位置

遥控器参数在：

```text
src/sim2real_bringup/config/runtime.yaml
```

当前默认参数：

```yaml
remote_enabled: true
remote_port: "/dev/ttyACM0"
remote_baudrate: 100000
remote_timeout: 0.02
remote_axis_deadzone: 50
remote_active_threshold: 50
remote_axis_full_scale: 660.0
remote_max_vx: 0.8
remote_max_vy: 0.3
remote_max_yaw_rate: 0.5
remote_invert_vx: true
remote_invert_vy: false
remote_invert_yaw: true
remote_publish_inactive_zero: true
remote_estop_latch: true
remote_estop_channel: 7
remote_estop_level: "high"
remote_estop_debounce_frames: 3
remote_estop_require_remote_mode: true
remote_poll_hz: 50.0
```

如果遥控器串口不是 `/dev/ttyACM0`，需要修改：

```yaml
remote_port: "/dev/ttyUSB0"
```

或改成实际设备路径。

## 4. 启动前检查

### 4.1 确认串口存在

```bash
ls /dev/ttyACM* /dev/ttyUSB*
```

如果使用默认配置，应能看到：

```bash
/dev/ttyACM0
```

### 4.2 确认串口权限

如果节点提示串口权限不足，可以临时执行：

```bash
sudo chmod 666 /dev/ttyACM0
```

更推荐的长期方式是把当前用户加入 `dialout` 组：

```bash
sudo usermod -aG dialout $USER
```

然后重新登录。

### 4.3 确认 Python serial 依赖

节点依赖 `pyserial`。如果系统没有安装：

```bash
sudo apt update
sudo apt install -y python3-serial
```

## 5. 构建

如果刚修改过代码或参数，建议重新构建相关包：

```bash
cd /path/to/sim2real_ros2_v3
source /opt/ros/humble/setup.bash
colcon build --packages-select sim2real_runtime sim2real_bringup --symlink-install --merge-install
```

构建完成后 source 环境：

```bash
source install/setup.bash
```

确认可执行节点存在：

```bash
ros2 pkg executables sim2real_runtime
```

应包含：

```text
sim2real_runtime remote_uart_node.py
```

## 6. 推荐启动方式

### 6.1 启动完整系统，不启动 Nav2

这是你当前常用方式：

```bash
cd /path/to/sim2real_ros2_v3
source /opt/ros/humble/setup.bash
source install/setup.bash
ros2 launch sim2real_bringup sim2real_system.launch.py launch_nav2:=false
```

默认情况下，`launch_remote:=true`，所以上面命令会同时启动遥控器节点。

等价完整写法：

```bash
ros2 launch sim2real_bringup sim2real_system.launch.py launch_nav2:=false launch_remote:=true
```

### 6.2 不启动遥控器

如果只想用手动 `ros2 topic pub` 或其他上位机发 `/cmd_vel`，可以关闭遥控器节点：

```bash
ros2 launch sim2real_bringup sim2real_system.launch.py launch_nav2:=false launch_remote:=false
```

## 7. 单独启动遥控器节点

如果系统已经在运行，只想单独测试遥控器节点：

```bash
cd /path/to/sim2real_ros2_v3
source /opt/ros/humble/setup.bash
source install/setup.bash
ros2 run sim2real_runtime remote_uart_node.py --ros-args --params-file src/sim2real_bringup/config/runtime.yaml
```

如果要临时指定串口：

```bash
ros2 run sim2real_runtime remote_uart_node.py --ros-args \
  --params-file src/sim2real_bringup/config/runtime.yaml \
  -p remote_port:=/dev/ttyUSB0
```

## 8. 执行后会产生什么效果

启动以下命令后：

```bash
ros2 launch sim2real_bringup sim2real_system.launch.py launch_nav2:=false
```

系统会产生以下效果。

### 8.1 启动硬件桥接节点

节点：

```text
/sim2real_hw_node
```

效果：

1. 打开 `can0` 和 `can1`。
2. 如果 `dry_run: false` 且 CAN 初始化成功，会使能 16 个 RobStride 电机。
3. 设置电机 MIT 模式。
4. 设置电机速度限制和力矩限制。
5. 以 `200Hz` 运行硬件读写循环。
6. 发布 `/runtime/state`。
7. 订阅 `/runtime/target` 执行策略目标。

### 8.2 启动策略运行节点

节点：

```text
/sim2real_runtime_node
```

效果：

1. 加载 ONNX 策略模型。
2. 订阅 `/runtime/state`。
3. 订阅 `/cmd_vel`。
4. 订阅 `/safety/estop`。
5. 执行启动站立流程：
   - `boot_hold`
   - `startup_soft_hold`
   - `startup_hold`
   - `runtime_zero_hold`
   - `runtime_policy`
6. 以 `50Hz` 发布 `/runtime/target`。

### 8.3 启动遥控器节点

节点：

```text
/sim2real_remote_uart_node
```

效果：

1. 打开默认串口 `/dev/ttyACM0`。
2. 以 `50Hz` 轮询 SBUS 数据。
3. 遥控器摇杆居中时持续发布零速度：

```text
/cmd_vel:
  linear.x = 0.0
  linear.y = 0.0
  angular.z = 0.0
```

4. 推动遥控器时发布非零速度，例如：

```text
/cmd_vel:
  linear.x = vx
  linear.y = vy
  angular.z = yaw
```

5. 当 CH7 打到高位时发布：

```text
/safety/estop: true
```

由于当前 `remote_estop_latch: true`，急停是锁存式行为：在 `REMOTE` 模式下，CH7 连续 3 帧有效高位后，节点会发布急停，并保持内部急停已触发状态。恢复运行通常需要重启系统或手动发布复位信号，并确认机器人安全。

### 8.4 机器人行为效果

正常启动后，机器人不会立即按策略行走，而是按阶段执行：

1. 电机使能。
2. 读取当前关节位置。
3. 软保持当前姿态。
4. 平滑过渡到默认站立姿态。
5. 稳定后进入 runtime。
6. 遥控器无输入时保持站立平衡，即 `runtime_zero_hold`。
7. 遥控器有输入时进入策略控制，即 `runtime_policy`。

也就是说：

| 遥控器状态 | 机器人效果 |
|---|---|
| 摇杆居中 | 站立保持，不主动行走 |
| CH2 前后推动 | 前进/后退 |
| CH4 左右推动 | 横向移动 |
| CH1 左右推动 | 原地转向 |
| CH7 高位 | 软件急停，进入安全刹车 |

## 9. 如何确认遥控器已经生效

### 9.1 查看节点是否存在

```bash
ros2 node list
```

应看到：

```text
/sim2real_remote_uart_node
/sim2real_runtime_node
/sim2real_hw_node
```

### 9.2 查看 `/cmd_vel`

```bash
ros2 topic echo /cmd_vel
```

摇动遥控器时应看到 `linear.x`、`linear.y` 或 `angular.z` 变化。

### 9.3 查看 `/safety/estop`

```bash
ros2 topic echo /safety/estop
```

CH7 高位时应看到：

```yaml
data: true
```

### 9.4 查看策略目标阶段

```bash
ros2 topic echo /runtime/target --field target_source
```

常见输出含义：

| `target_source` | 含义 |
|---|---|
| `boot_hold` | 刚启动，保持初始姿态 |
| `startup_soft_hold` | 启动软保持 |
| `startup_hold` | 正在站立或站立后保持 |
| `runtime_zero_hold` | 已进入 runtime，遥控器无有效输入 |
| `runtime_policy` | 遥控器有输入，策略已经介入 |
| `safety_brake` | 安全刹车 |
| `timeout_hold` | 目标超时，硬件保持默认姿态 |

### 9.5 查看完整目标状态

```bash
ros2 topic echo --once /runtime/target
```

重点关注字段：

```yaml
target_source:
zero_command:
runtime_released:
release_alpha:
command:
raw_command:
```

如果遥控器摇杆有输入，通常会看到：

```yaml
target_source: runtime_policy
zero_command: false
runtime_released: true
release_alpha: 1.0
```

## 10. 常见问题

### 10.1 启动后提示无法打开串口

可能原因：

1. 串口路径不对。
2. 权限不足。
3. 设备没有插好。
4. 设备被其他程序占用。

检查：

```bash
ls /dev/ttyACM* /dev/ttyUSB*
```

修改 `runtime.yaml`：

```yaml
remote_port: "/dev/ttyUSB0"
```

### 10.2 `/cmd_vel` 没有变化

检查：

```bash
ros2 node list
ros2 topic echo /cmd_vel
```

如果节点存在但无变化，可能是：

1. 遥控器没有输出 SBUS。
2. 串口波特率不对。
3. SBUS 接线错误。
4. 遥控器通道未校准。
5. 死区 `remote_axis_deadzone` 或 `remote_active_threshold` 太大。

### 10.3 摇杆方向反了

修改：

```yaml
remote_invert_vx: true
remote_invert_vy: false
remote_invert_yaw: true
```

例如前后方向反了，就切换：

```yaml
remote_invert_vx: false
```

### 10.4 急停后不恢复

当前配置：

```yaml
remote_estop_latch: true
```

这表示急停锁存。触发后建议：

1. 先确认机器人物理安全。
2. 停止 launch。
3. 将 CH7 打回安全位置。
4. 重新启动系统。

如果需要非锁存模式，可以改为：

```yaml
remote_estop_latch: false
```

但实机调试时更建议使用锁存模式。

## 11. 快速验证命令清单

```bash
cd /path/to/sim2real_ros2_v3
source /opt/ros/humble/setup.bash
source install/setup.bash

ros2 launch sim2real_bringup sim2real_system.launch.py launch_nav2:=false
```

另开终端：

```bash
cd /path/to/sim2real_ros2_v3
source /opt/ros/humble/setup.bash
source install/setup.bash

ros2 node list
ros2 topic echo /cmd_vel
ros2 topic echo /runtime/target --field target_source
```

如果只测遥控器，不启动电机系统：

```bash
ros2 run sim2real_runtime remote_uart_node.py --ros-args --params-file src/sim2real_bringup/config/runtime.yaml
```

另开终端：

```bash
ros2 topic echo /cmd_vel
ros2 topic echo /safety/estop
```

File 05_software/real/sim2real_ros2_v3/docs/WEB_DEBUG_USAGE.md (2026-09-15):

# sim2real_ros2_v3 Web UDP 调试说明

本文档说明本次新增的最小 Web 调试链路。

## 1. 架构

```text
Windows 本地浏览器/HTTP 服务
        |
        | UDP JSON
        v
Nano: sim2real_web_udp_bridge_node.py
        |
        | ROS 2 topics
        v
sim2real_cmd_mux_node.py -> /cmd_vel -> sim2real_runtime_node
```

Web 页面在 Windows 本地渲染，Nano 只运行轻量 UDP bridge 和 ROS2 节点。

## 2. 新增 ROS2 节点

### `remote_uart_node.py`

遥控器节点现在发布：

```text
/cmd_vel_remote
```

不再直接发布 `/cmd_vel`。

通道触发阈值改为：

```yaml
remote_axis_deadzone: 40
remote_active_threshold: 40
```

只有通道归一化值绝对值大于 `40` 才认为是有效输入。

### `cmd_mux_node.py`

输入：

```text
/cmd_vel_remote
/cmd_vel_web
/cmd_vel_nav
/control/mode
/remote/enabled
/web/enabled
/nav/enabled
/safety/estop
```

输出：

```text
/cmd_vel
/control/mode_state
/control/mux_status
```

控制模式：

```text
DISABLED
REMOTE
WEB
NAV
```

急停 `/safety/estop=true` 会强制进入 `DISABLED`，并输出零速度。

### `web_udp_bridge_node.py`

Nano 端 UDP 监听：

```text
0.0.0.0:15000
```

发布：

```text
/cmd_vel_web
/safety/estop
/control/mode
/web/enabled
/remote/enabled
/nav/enabled
```

订阅并回传状态：

```text
/runtime/state
/runtime/target
/cmd_vel
/safety/estop
/control/mode_state
/control/mux_status
```

## 3. Nano 启动

```bash
cd /path/to/sim2real_ros2_v3
source /opt/ros/humble/setup.bash
source install/setup.bash
ros2 launch sim2real_bringup sim2real_system.launch.py launch_nav2:=false
```

默认会启动：

```text
sim2real_remote_uart_node
sim2real_cmd_mux_node
sim2real_web_udp_bridge_node
```

如果不想启动 Web UDP bridge：

```bash
ros2 launch sim2real_bringup sim2real_system.launch.py launch_nav2:=false launch_web_bridge:=false
```

## 4. Windows 本地 Web 启动

把目录复制到 Windows 或通过共享目录访问：

```text
tools/win_web_debug
```

在 Windows 上安装 Python 3 后运行：

```bash
python server.py --nano-host <Nano_IP> --http-port 8088 --udp-port 15001
```

浏览器打开：

```text
http://127.0.0.1:8088
```

## 5. UDP 命令格式

### 切换模式

```json
{"type":"mode","mode":"REMOTE"}
```

```json
{"type":"mode","mode":"WEB"}
```

```json
{"type":"mode","mode":"DISABLED"}
```

### Web 速度控制

```json
{
  "type": "cmd_vel",
  "linear": {"x": 0.2, "y": 0.0, "z": 0.0},
  "angular": {"x": 0.0, "y": 0.0, "z": 0.1}
}
```

Nano 端会再次限幅：

```text
vx  <= ±0.8 m/s
vy  <= ±0.3 m/s
yaw <= ±0.5 rad/s
```

### 零速度

```json
{"type":"zero"}
```

### 软急停

```json
{"type":"estop","data":true}
```

## 6. 安全保护

当前最小版本已经包含：

1. 遥控器误触发阈值：`40`。
2. 遥控器/Web/Nav 互斥控制模式。
3. `cmd_mux` 二次限幅。
4. `cmd_mux` 加速度限制。
5. Web UDP 超时自动发布零速度。
6. 急停优先级最高。
7. Web 页面切换到 `WEB` 模式需要确认。
8. Web 松开虚拟摇杆会自动发送零速度。

建议实机调试流程：

1. 先点击 `DISABLED`。
2. 确认 `/cmd_vel` 为零。
3. 如果使用遥控器，点击 `REMOTE`。
4. 如果使用 Web，点击 `WEB` 并确认周围安全。
5. 一旦异常，立即点击 `软急停`。

## 7. 验证命令

查看最终输出速度：

```bash
ros2 topic echo /cmd_vel
```

查看遥控器输入：

```bash
ros2 topic echo /cmd_vel_remote
```

查看 Web 输入：

```bash
ros2 topic echo /cmd_vel_web
```

查看当前仲裁模式：

```bash
ros2 topic echo /control/mode_state
```

查看策略状态：

```bash
ros2 topic echo /runtime/target --field target_source
```

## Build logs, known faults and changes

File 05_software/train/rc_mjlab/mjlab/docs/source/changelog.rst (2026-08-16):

=========
Changelog
=========

Upcoming version (not yet released)
-----------------------------------

Added
^^^^^

- Added ``BuiltinDcMotorActuator``, a native MuJoCo ``<dcmotor>`` wrapper.
  Supports voltage / position / velocity input modes with back-EMF,
  configurable motor constants, and optional integral, slew, inductance,
  thermal, LuGre, and cogging extensions.
- Added ``scale_with_difficulty`` to ``HfRandomUniformTerrainCfg``. When
  enabled, the noise amplitude scales with difficulty (flat at 0, full
  ``noise_range`` at 1) so the terrain progresses in a curriculum. Defaults to
  ``False``, preserving the previous difficulty-independent behavior.

Changed
^^^^^^^

- Bumped ``rsl-rl-lib`` from 5.2.0 to 5.4.0.
- Curriculum-mode terrain difficulty is now deterministic across rows
  and reaches the configured ``difficulty_range`` endpoints
  (:issue:`1027`).
- Heightfield terrains now color by absolute height with a diverging palette
  (cool below the ground plane, green at ground level, warm above) on a fixed
  scale, replacing the per-patch normalization. Color is now consistent across
  terrains, and low-amplitude terrain such as ``random_rough`` reads as gently
  tinted ground instead of high-contrast noise.
- ``BoxNestedRingsTerrainCfg`` now builds uniform-height concentric ridges
  whose separating gaps widen with difficulty, replacing the random per-ring
  heights. Rings are colored by height (like the other terrains) and the outer
  border matches the ring height.
- Terrain generation no longer prints timing information to stdout.

Fixed
^^^^^

- Fixed ``select_gpus`` crashing when ``CUDA_VISIBLE_DEVICES`` contains MIG UUIDs instead of numeric indices.
- Fixed pyramid-stairs terrains (``BoxPyramidStairsTerrainCfg``,
  ``BoxInvertedPyramidStairsTerrainCfg``, and ``BoxOpenStairsTerrainCfg``)
  leaving an empty, geometry-free border at difficulty 0, where the step
  height collapses to zero. The flat border frame is now always generated as
  solid geometry flush with the ground (:issue:`1033`).
- Fixed ``HfPerlinNoiseTerrainCfg`` failing to compile at difficulty 0, where
  the target height collapses to zero and MuJoCo rejects the non-positive
  heightfield size.
- Fixed ``BoxRandomGridTerrainCfg`` producing NaN colors (and failing to build)
  at difficulty 0, where the grid height is zero and the color normalization
  divided by zero.
- Fixed the center platform z-fighting with surrounding geometry in
  ``BoxRandomGridTerrainCfg`` (grid cells were left underneath the platform) and
  ``BoxRandomSpreadTerrainCfg`` (the platform duplicated the floor surface).
- Fixed ``BoxNarrowBeamsTerrainCfg`` square platform corners protruding between
  the beams at high difficulty; the platform now shrinks to stay within the
  beams' angular coverage.
- Fixed ``BoxSteppingStonesTerrainCfg`` reconfiguring abruptly at a difficulty
  threshold, where the stone grid re-tiled as its spacing crossed an integer
  boundary, and leaving an oversized gap around the center platform. The grid is
  now difficulty-independent and the platform snaps to it as a clean island.
- Fixed ``train --video``, ``play``, and ``demo`` crashing with ``OpenGL
  platform library not loaded`` on headless Linux hosts that don't pre-set
  ``MUJOCO_GL``. The default is now applied in ``mjlab/__init__.py`` (Linux
  only) so it takes effect before mujoco's GL backend selection runs.

Version 1.4.0 (May 26, 2026)
----------------------------

Added
^^^^^

- Added ``BuiltinPdActuator``, the implicit-integration version of
  ``IdealPdActuator``. Same interface (position + velocity targets,
  kp/kd gains), but expresses the PD as native MuJoCo ``<position>``
  and ``<velocity>`` elements so the ``implicit`` / ``implicitfast``
  integrators include the kp/kd derivatives in their velocity update.
  The actuator stays stable at gain/timestep combinations where
  explicit Python PD would diverge, which matters when you want to
  run a real motor's stiff on-board PD gains in sim. ``effort_limit``
  is enforced as a sum-clamp on the two PD terms via
  ``jnt_actfrcrange`` (or ``tendon_actfrcrange``). Supported by
  ``dr.pd_gains`` and ``dr.effort_limits``.
- Added ``mdp.projected_gravity_from_sensor``, an observation that derives
  projected gravity from a ``framezaxis`` up-vector sensor (negated) rather
  than from the root body orientation. Unlike ``mdp.projected_gravity``, it
  reflects the sensor's site frame, so it can observe IMU mounting domain
  randomization (e.g. via ``dr.site_quat``). Go1 and G1 ship an
  ``imu_upvector`` sensor for this.
- Added ``DebugVisualizer.add_box`` for drawing an axis-oriented box
  primitive, mirroring ``add_ellipsoid``. Supported by both the native
  and Viser viewers. ``size`` is the box half-extents (:issue:`992`).
- Added ``--log-root`` CLI option to ``train``, ``play``, and ``evaluate``
  scripts for choosing where training logs are stored. Defaults to
  ``logs/rsl_rl`` (unchanged behavior). Useful for directing outputs to a
  scratch disk or shared mount.
- ``RewardManager``, ``TerminationManager``, and ``MetricsManager`` now
  validate that every term function returns a tensor of shape
  ``(num_envs,)`` when evaluated, raising a clear ``ValueError``
  naming the offending term instead of silently broadcasting or crashing
  with an opaque error later during training.
- Added ``ContactSensor.primary_names`` property to expose the resolved
  primary names in the order they appear along the per-contact axis of the
  output tensors. This makes it possible to map a contact-data column back
  to the primary it belongs to (:issue:`914`).
- Added per-world mesh variant support via ``VariantEntityCfg``. Each
  world in a batched simulation can now use a different mesh asset for
  the same logical entity (e.g. world 0 holds a cube, world 1 a
  sphere). Variants are passed as a ``dict[str, Callable]`` of named
  spec callables; the optional ``assignment`` field controls how worlds
  map to variants and accepts ``None`` (uniform), a ``dict[str, float]``
  of per-variant weights, or a custom ``Callable[[int], Sequence[int]]``.
  Mesh-derived constants (collision bounds, body inertials, subtree
  mass, inverse weights) are compiled per-variant and stored as
  per-world arrays in the Warp model, so domain randomization, the
  native viewer, the offscreen renderer, and the Viser viewer all pick
  up the variant assignment automatically. Variants must share the
  same kinematic structure (same bodies, joints, joint types); only
  mesh geoms may differ. Assignment is fixed at simulation init. See
  :ref:`heterogeneous_worlds` for usage. With help from @XiangruiJiang.
- Per-world mesh variants now support per-variant materials and textures.
  Each variant can reference its own named material, which is automatically
  prefixed and scattered via ``geom_matid`` alongside the existing
  ``geom_dataid`` table. Variants without a material get ``matid = -1``.
  Contribution by @omarrayyann.

Changed
^^^^^^^

- ``Entity`` now raises a clear error at construction when its spec contains
  more than one freejoint. An entity models a single system rooted at one
  body, so it has at most one freejoint; a second one was previously accepted
  silently and only surfaced later as a cryptic shape mismatch when writing
  root state. Model each detached floating body as its own entry in
  ``SceneCfg.entities`` instead.
- Changed ``compute_root_relative_mpkpe`` to re-anchor the reference to the
  robot's root each step, removing yaw drift as well as translation so it
  measures intrinsic body pose error.
- Changed ``compute_joint_velocity_error`` from an L2 norm to a per-joint
  RMS, so it no longer scales with the number of joints.
- Bumped ``mujoco`` to 3.8 and ``mujoco-warp`` to 3.8.0. The ``multiccd``
  enable flag was removed in mujoco 3.8 (it became default-on), so configs
  that listed ``"multiccd"`` in ``MujocoCfg.enableflags`` need to drop it.
- Camera segmentation now matches ``mujoco_warp``'s typed segmentation
  output. ``CameraSensorData.segmentation`` stores ``(object_id,
  object_type)`` pairs in shape ``[B, H, W, 2]`` instead of the previous
  legacy geom-id-only layout. Contribution by @tkelestemur.
- Sped up ``RayCaster`` post-processing by removing boolean-mask indexing
  operations and replacing them with ``masked_fill_`` plus a clamped-distance
  formulation of ``hit_pos_w`` that places misses at the world origin. This
  removes all CUDA syncs from the ray post-process, letting the CPU thread
  proceed while GPU-based sensing runs. Contribution by @bd-pdomanico.
- Bumped ``rsl-rl-lib`` from 5.0.1 to 5.2.0. This brings ``torch.compile`` support for
  PPO and Distillation, and optional std clamping and constant std in
  ``GaussianDistribution``. No code changes required on the mjlab side.
- ``TerrainEntityCfg`` debug visualization sites (environment origins,
  terrain origins, flat patches) are now off by default. Set
  ``debug_vis=True`` to re-enable them. The sites inflated ``nsite`` and
  caused a measurable slowdown in the per-step ``site_local_to_global``
  kernel (:issue:`942`).
- Task package load failures during ``mjlab`` import now print the full
  traceback (and the entry point's module path) to ``stderr`` instead of
  just the exception message, making it easier to pinpoint the source of
  import errors when running commands like ``list-envs`` (:issue:`910`).
  Contribution by @saikishor.
- Clarified ``ContactSensor`` shape conventions: per-contact fields
  (``found``, ``force``, ``torque``, ``dist``, ``pos``, ``normal``,
  ``tangent``) have shape ``[B, P * num_slots, ...]`` while per-primary
  air-time fields (``current_air_time``, ``last_air_time``,
  ``current_contact_time``, ``last_contact_time``) have shape ``[B, P]``,
  where ``P`` is the number of resolved primaries (:issue:`914`).
- Event functions now share a single ``resolve_env_ids`` helper to expand
  ``env_ids=None`` to all environments, replacing five copies of the same
  guard. ``push_by_setting_velocity`` and ``apply_external_force_torque``
  accept ``env_ids=None`` too, so they work as global-time interval terms.
  Documented when to use ``apply_external_force_torque`` (a constant,
  self-managed wrench) versus ``apply_body_impulse`` (transient, automatic
  impulses) versus ``push_by_setting_velocity`` (an instantaneous velocity
  kick).

Fixed
^^^^^

- Removed use of deprecated ``warp-lang`` symbols (``wp.context.runtime``
  and ``wp.context.Device``) that were dropped in newer ``warp-lang``
  releases, causing ``AttributeError: module 'warp' has no attribute
  'context'`` at import/runtime. mjlab now uses
  ``wp.get_cuda_driver_version()`` and ``wp.Device`` instead
  (:issue:`967`). Contribution by @rdeits.
- Fixed the tracking ``evaluate`` script scoring each metric against the
  next motion frame; the reference is now snapshotted before each step to
  match the reward.
- Fixed the tracking end-effector metrics silently scoring zero for an
  unknown body name; they now raise ``ValueError``.
- Fixed ``compute_mpkpe`` measuring root-relative instead of global error;
  it now uses the global reference ``body_pos_w`` (:issue:`1006`).
- Fixed heavy flicker in offscreen training videos on rough-terrain tasks.
  The renderer recomputed its context "neighbor" robots every frame from
  ``env_origins``, which the terrain curriculum mutates on reset, so the
  neighbor set kept changing and robots popped in and out. The neighbor
  set is now computed once and cached (:issue:`979`).
- Fixed command delay only applying to an actuator's position target.
  ``IdealPdActuator`` and ``DcMotorActuator`` also use velocity and effort, which
  arrived undelayed and out of sync; all command targets now share one delay.
  Zero-reference setups are unaffected.
- Fixed duplicate random seeds across nodes in multi-node training. The
  per-process seed offset in ``scripts/train.py`` now uses the global
  ``RANK`` instead of ``LOCAL_RANK``. Contribution by @bd-pdomanico.
- Fixed ``apply_body_impulse`` firing an impulse on the very first step (and
  the first step after every reset) instead of starting with a cooldown as
  documented. The cooldown is now sampled lazily on the first call so impulse
  timing is decorrelated from episode resets (:issue:`973`).
- Fixed ``dr.pd_gains`` and ``dr.effort_limits`` silently no-oping when
  passed an ``Operation`` object (e.g. ``dr.scale``) instead of a string.
  Both functions now accept ``Operation | str`` like every other DR event
  and raise ``ValueError`` for unsupported operations (:issue:`971`).
- Fixed ``ContactSensor`` with ``global_frame=True`` and
  ``reduce`` ∈ {``"none"``, ``"mindist"``, ``"maxforce"``} producing forces
  rotated onto the wrong axis. The contact-frame→world rotation matrix had
  its columns ordered ``[tangent, tangent2, normal]`` instead of
  ``[normal, tangent, tangent2]``, projecting the normal-force component
  onto a tangent direction. Contribution by @bd-pdomanico.
- Fixed ``extras["log"]`` entries written by reward terms (e.g. ``Metrics/*``
  values in velocity tasks) being silently discarded on any step where at
  least one environment resets. ``_reset_idx`` was clearing the dict after
  ``reward_manager.compute()`` had already populated it. The clear now
  happens at the top of ``step()`` and ``reset()`` so that all entries
  survive (:issue:`957`).
- Fixed ``ContactSensor.compute_first_contact`` and ``compute_first_air``
  occasionally missing events when a contact began or ended right at the
  last physics substep of a control step. ``current_contact_time`` /
  ``current_air_time`` accumulate in float32 and can drift a few ULPs past
  ``dt``, but the default ``abs_tol`` of ``1e-8`` sat at the noise floor
  and rejected the comparison. Raised the default to ``1e-6``, which stays
  well below typical control ``dt`` while comfortably covering float32
  accumulation noise (:issue:`933`). Contribution by @paLeziart.
- Fixed ``out_of_terrain_bounds`` using stale terrain dimensions. It read
  ``TerrainGeneratorCfg.num_cols`` directly, which is ignored in curriculum
  mode (the generator uses ``len(sub_terrains)`` columns instead), and it
  did not account for ``border_width``. The termination now reads the
  effective grid shape from ``terrain.terrain_origins`` and includes the
  border in the footprint, so robots no longer reset while still on valid
  terrain (or fail to reset after running off it) (:issue:`923`).
- ``ObservationManager`` now skips observation groups that end up with
  zero active terms (e.g. all terms set to ``None``) with a log message,
  instead of crashing later in ``torch.stack``/``torch.cat``. This lets
  a shared runner config define groups that become empty under certain
  runtime flags (e.g. model-specific terms all disabled for one variant).
  The whole group can still be set to ``None`` to disable it explicitly.
- Fixed a runtime broadcast error in ``ContactSensor`` when combining
  ``num_slots > 1`` with ``track_air_time=True`` and more than one primary.
  Air-time tracking now reduces ``found`` across slots so that a primary is
  considered in contact when any of its slots reports a match (:issue:`914`).
- Updated the ``create_new_task.ipynb`` Colab tutorial to import
  ``XmlActuatorCfg`` instead of the removed ``XmlVelocityActuatorCfg``.
  Added a regression test (``tests/test_notebooks.py``) that parses each
  notebook cell and verifies that every ``from mjlab... import X``
  reference resolves, so future renames in the mjlab public API can't
  silently rot the tutorials (:issue:`913`).
- Fixed ``ObservationManager`` silently sharing a single ``NoiseModelCfg``
  instance across observation groups that declared terms with the same
  name. ``_group_obs_class_instances`` was keyed by term name alone, so
  the last group processed in ``_prepare_terms`` overwrote earlier
  groups' instances. Symptoms included the wrong noise config being
  applied, shared per-episode state for ``NoiseModelWithAdditiveBias``
  (e.g. bias drawn from the wrong ``bias_noise_cfg``), and missed
  ``reset()`` calls for overwritten instances. Instances are now keyed
  by ``(group_name, term_name)`` so each group owns its own noise model.
- Fixed ``CurriculumManager.get_active_iterable_terms`` raising
  ``TypeError`` when a term's state was a dict. The dict branch indexed
  the output list by term name instead of appending to the local ``data``
  list. No in-tree caller currently invokes this method, so the bug was
  latent.

Version 1.3.0 (April 14, 2026)
------------------------------

Added
^^^^^

- Added ``ManagerBasedRlEnvCfg.auto_reset`` flag. When ``True`` (default),
  ``step()`` continues to reset done environments in place and returns the
  post-reset observation. When ``False``, ``step()`` skips the reset block
  and returns the terminal observation directly; the caller must call
  ``reset(env_ids=...)`` for done environments before the next ``step()``
  or a ``RuntimeError`` is raised. Enables access to the true terminal
  state for algorithms that need it. Note that mjlab's bundled ``train.py``
  uses rsl_rl's ``OnPolicyRunner``, which does not drive manual resets, so
  ``auto_reset=False`` is intended for custom training loops (:issue:`900`).
- Added ``ActuatorCfg.viscous_damping`` for passive velocity proportional
  damping (``f = -b·v``), distinct from the PD derivative gain ``damping``
  used by position and velocity actuators. Maps to ``<joint damping>`` for
  JOINT transmission and ``<tendon damping>`` for TENDON transmission.
  Defaults to ``None`` (preserves the XML value).
- Added :class:`~mjlab.managers.RecorderManager` for logging observations,
  actions, or arbitrary environment data during rollouts. Implement a
  :class:`~mjlab.managers.RecorderTerm` subclass and register it in the
  ``recorders`` dict on ``ManagerBasedRlEnvCfg``. The manager provides
  ``record_pre_reset``, ``record_post_reset``, and ``record_post_step``
  lifecycle hooks with no opinion on how data is stored.
- Added :func:`~mjlab.envs.mdp.curriculums.termination_curriculum` for
  scheduling changes to termination term parameters during training,
  matching the existing ``reward_curriculum`` pattern. Both now share a
  single internal engine with init-time validation of stage ordering,
  field existence, and param keys.
- Added ``reduce`` field to ``MetricsTermCfg``. Setting ``reduce="last"``
  reports the value from the final step of the episode rather than the
  episode mean, which is useful for binary success metrics.
- Added :class:`~mjlab.envs.mdp.actions.RelativeJointPositionAction` for
  joint position control relative to the current configuration. The target is
  ``current_pos + action * scale``, so a zero action holds the current
  configuration rather than commanding the default pose.
- Added :func:`~mjlab.envs.mdp.dr.pair_friction` for randomizing geom-pair
  friction overrides (``pair_friction`` in ``mjModel``), with an
  ``isotropic=True`` option that mirrors the symmetric tangent and roll
  axes so single-axis randomization does not leave the paired axis stale.
- Added ``STAIRS_TERRAINS_CFG`` terrain preset for progressive stair
  curriculum training and ``@terrain_preset`` decorator for composing
  terrain configurations from reusable presets.
- Added cartpole balance and swingup tasks (``Mjlab-Cartpole-Balance`` and
  ``Mjlab-Cartpole-Swingup``) with a :ref:`tutorial <tutorial-cartpole>`
  that walks through building an environment from scratch.
- Added :ref:`motion imitation <motion-imitation>` documentation with
  preprocessing instructions. The README now links here instead of the
  BeyondMimic repository, which produced incompatible NPZ files when used
  with mjlab (:issue:`777`).
- Added ``margin``, ``gap``, and ``solmix`` fields to ``CollisionCfg``
  for per geom contact parameter configuration (:issue:`766`).
- NaN guard now captures mocap body poses (``mocap_pos``, ``mocap_quat``)
  when the model has mocap bodies, enabling full state reconstruction in
  the dump viewer for fixed-base entities.
- Implemented ``ActionTermCfg.clip`` for clamping processed actions after
  scale and offset (:issue:`771`).
- Added ``qfrc_actuator`` and ``qfrc_external`` generalized force accessors
  to ``EntityData``. ``qfrc_actuator`` gives actuator forces in joint space
  (projected through the transmission). ``qfrc_external`` recovers the
  generalized force from body external wrenches (``xfrc_applied``)
  (:issue:`776`).
- Added ``RewardBarPanel`` to the Viser viewer, showing horizontal bars for
  each reward term with a running mean over ~1 second (:issue:`800`).
- Added ``per_substep`` flag to ``MetricsTermCfg`` for evaluating metrics
  once per physics substep inside the decimation loop. The per substep
  values are averaged within each environment step, so episode averages
  remain comparable to regular per step metrics.
- Added ``project-instinct/InstinctMJ`` to the research page's list of
  projects built on mjlab.
- Added a Checkpoints tab to the Viser play viewer for hot-swapping
  checkpoints without restarting. Works with local directories and W&B
  runs (:issue:`751`). Contribution by @omarrayyann.
- Added ``"segmentation"`` camera data type for per-pixel geom ID output
  alongside RGB and depth, and a multi-cube goal-conditioned lifting task
  (``Mjlab-Multi-Cube-Seg-Yam``) that uses it (:issue:`862`).
  Contribution by @pthangeda.

Changed
^^^^^^^

- Renamed the ``list_envs`` console script to ``list-envs`` for consistency
  with the other hyphenated entry points (``viz-nan``, ``export-scene``).
  Invoke via ``uv run list-envs``.
- ``ActuatorCfg.armature`` and ``ActuatorCfg.frictionloss`` now default to
  ``None`` instead of ``0.0``. ``None`` preserves the value defined in the
  XML. Previously, builtin actuators would silently overwrite XML joint and
  tendon properties with zero when these fields were not explicitly set.
  To restore the old behavior, pass ``armature=0.0`` or ``frictionloss=0.0``
  explicitly.
- Actuator delay is now configured inline on any ``ActuatorCfg`` subclass
  (e.g. ``BuiltinPositionActuatorCfg(..., delay_min_lag=2, delay_max_lag=5)``)
  instead of wrapping with ``DelayedActuatorCfg``. ``DelayedActuator``,
  ``DelayedActuatorCfg``, and ``DelayedBuiltinActuatorGroup`` are removed.
- Removed ``delay_target`` from ``ActuatorCfg``. Delay now always applies to
  the actuator's ``command_field`` automatically. Multi-target delay
  (``delay_target=("position", "velocity")``) is no longer supported.
- ``XmlPositionActuatorCfg``, ``XmlVelocityActuatorCfg``, ``XmlMotorActuatorCfg``,
  and ``XmlMuscleActuatorCfg`` are replaced by a single ``XmlActuatorCfg`` that auto
  detects the actuator type from XML. Pass ``command_field=...`` to override detection.
- Replaced the viser viewer internals with the ``mjviser`` package. Scene
  creation, mesh conversion, and overlay rendering (contacts, forces,
  inertia, tendons, joints, frames) are now provided by mjviser. The viewer
  exposes a new Visualization tab for overlay controls and a Groups tab for
  geom/site visibility. Debug visualization and warp tensor conversion remain
  in mjlab's ``MjlabViserScene`` subclass (:issue:`839`).
- In curriculum terrain mode, each terrain type now gets exactly one column
  (``num_cols`` is set to ``len(sub_terrains)``). The ``proportion`` field
  now controls robot spawning distribution across columns rather than column
  count. Random mode is unchanged (:issue:`811`).
- ``BoxSteppingStonesTerrainCfg`` stone size now decreases with difficulty,
  interpolating from the large end of ``stone_size_range`` at difficulty 0
  to the small end at difficulty 1 (:issue:`785`).
- Removed deprecated ``TerrainImporter`` and ``TerrainImporterCfg`` aliases.
  Use ``TerrainEntity`` and ``TerrainEntityCfg`` instead (:issue:`667`).
- ``Entity.clear_state()`` is deprecated. Use ``Entity.reset()`` instead.
  ``clear_state`` only zeroed actuator targets without resetting actuator
  internal state (e.g. delay buffers), which could cause stale commands
  after teleporting the robot to a new pose.
- Removed ``EntityData.generalized_force``. The property was bugged (indexed
  free joint DOFs instead of articulated DOFs) and the name was ambiguous.
  Use ``qfrc_actuator`` or ``qfrc_external`` instead (:issue:`776`).
- ``get_wandb_checkpoint_path`` now filters checkpoints server-side via the
  ``pattern`` parameter, avoiding unnecessary pagination and tolerance to
  corrupted metadata (:issue:`898`).

Fixed
^^^^^

- ``train`` and ``play`` now print a top-level usage message when invoked
  with ``-h`` / ``--help`` and no task argument, pointing users at
  ``list-envs`` and ``<TASK> --help`` (:issue:`905`).
- Fixed ghost geom filtering in the Viser viewer. Ghost geoms were selected
  by collision flags, so collision-disabled robot geoms appeared as ghosts.
  The viewer now uses visual alpha to determine which geoms to render.
- Scene now warns when an attached entity or terrain spec has non-default
  ``<option>`` fields (e.g. ``<flag contact="disable"/>``), which are
  silently dropped by ``MjSpec.attach()``. Use ``MujocoCfg`` to set
  simulation options instead (:issue:`885`).
- Fixed ``SceneEntityCfg`` names and IDs ordering mismatch when
  ``preserve_order=False`` (:issue:`876`). Contribution by @jsw7460.
- Fixed ONNX export path resolution in the velocity, manipulation, and
  tracking runners when a parent directory name contains the word
  ``"model"`` (:issue:`867`). Contribution by @gokulp01.
- ``export-scene`` now writes only referenced assets and places them
  correctly under the output directory. Previously, asset keys containing
  path traversal could write files outside the output directory, and all
  spec assets were included regardless of whether the scene XML referenced
  them (:issue:`858`).
- ``electrical_power_cost`` now uses ``qfrc_actuator`` (joint space) instead
  of ``actuator_force`` (actuation space) for mechanical power computation.
  Previously the reward was incorrect for actuators with gear ratios other
  than 1 (:issue:`776`).
- ``create_velocity_actuator`` no longer sets ``ctrllimited=True`` with
  ``inheritrange=1.0``. This caused a ``ValueError`` for continuous joints
  (e.g. wheels) that have no position range defined (:issue:`787`).
- ``write_root_com_velocity_to_sim`` no longer fails with tensor ``env_ids``
  on floating base entities (:issue:`793`).
- Joint limits for unlimited joints are now set to [-inf, inf] instead of
  [0, 0]. Previously the zero range caused incorrect clamping for entities
  with unlimited hinge or slide joints.
- Contact force visualization now copies ``ctrl`` into the CPU ``MjData``
  before calling ``mj_forward``. Actuators that compute torques in Python
  (``DcMotorActuator``, ``IdealPdActuator``) previously showed incorrect
  contact forces because the viewer ran with ``ctrl=0``
  (:issue:`786`).
- ``BoxSteppingStonesTerrainCfg`` no longer creates a large gap around the
  platform. Stones are now only skipped when their center falls inside the
  platform; edges that extend under the platform are allowed since the
  platform covers them (:issue:`785`).
- ``dr.pseudo_inertia`` no longer loads cuSOLVER, eliminating ~4 GB of
  persistent GPU memory overhead. Cholesky and eigendecomposition are now
  computed analytically for the small matrices involved (4x4 and 3x3)
  (:issue:`753`).
- Set terrain geom mass to zero so that the static terrain body does not
  inflate ``stat.meanmass``, which made force arrow visualization invisible
  on rough terrain (:issue:`734`, :issue:`537`).
- Native viewer now syncs ``qpos0`` when domain randomized, fixing incorrect
  body positions after ``dr.joint_default_pos`` randomization
  (:issue:`760`).
- ``command_manager.compute()`` is now called during ``reset()`` so that
  derived command state (e.g. relative body positions in tracking
  environments) is populated before the first observation is returned
  (:issue:`761`).
- ``RayCastSensor`` with ``ray_alignment="yaw"`` or ``"world"`` now correctly
  aligns the frame offset when attached to a site or geom with a local offset
  from its parent body. Previously only ray directions and pattern offsets were
  aligned, causing the frame position to swing with body pitch/roll
  (:issue:`775`).

Version 1.2.0 (March 6, 2026)
-----------------------------

.. admonition:: Breaking API changes
   :class: attention

   - ``randomize_field`` no longer exists. Replace calls with typed functions
     from the new ``dr`` module (e.g. ``dr.geom_friction``, ``dr.body_mass``).
   - ``EventTermCfg`` no longer accepts ``domain_randomization``. The
     ``@requires_model_fields`` decorator on each ``dr`` function takes care
     of field expansion automatically.
   - ``Scene.to_zip()`` is deprecated. Use ``Scene.write(path, zip=True)``.
   - ``RslRlModelCfg`` no longer accepts ``stochastic``, ``init_noise_std``,
     or ``noise_std_type``. Use ``distribution_cfg`` instead
     (e.g. ``{"class_name": "GaussianDistribution", "init_std": 1.0,
     "std_type": "scalar"}``). Existing checkpoints are automatically
     migrated on load.

Added
^^^^^

- Added ``"step"`` event mode that fires every environment step.
- Added ``apply_body_impulse`` event for applying transient external wrenches
  to bodies with configurable duration and optional application point offset.
- ONNX auto-export and metadata attachment for manipulation tasks (lift cube)
  on every checkpoint save, matching the velocity and tracking task behavior.
- Multi-frame ``RayCastSensor``: pass a tuple of ``ObjRef`` to ``frame`` for
  per-site raycasting with independent body exclusion. New properties:
  ``num_frames``, ``num_rays_per_frame``. New ``RayCastData`` fields:
  ``frame_pos_w`` and ``frame_quat_w``.
- ``RingPatternCfg`` ray pattern for concentric ring sampling around each
  frame.
- ``TerrainHeightSensor``, a ``RayCastSensor`` subclass that computes
  per-frame vertical clearance above terrain (``sensor.data.heights``).
  Velocity task configs now use it for ``feet_clearance``,
  ``feet_swing_height``, and ``foot_height``, replacing the previous
  world-Z proxy that was incorrect on rough terrain.
- Cloud training support via `SkyPilot <https://skypilot.readthedocs.io/>`_
  and Lambda Cloud, with documentation covering setup, monitoring, and
  cost management.
- W&B hyperparameter sweep scripts that distribute one agent per GPU
  across a multi-GPU instance.
- Contributing guide with documentation for shared Claude Code commands
  (``/update-mjwarp``, ``/commit-push-pr``).
- Added optional ``ViewerConfig.fovy`` and apply it in native viewer camera
  setup when provided.
- Native viewer now tracks the first non-fixed body by default (matching
  the Viser viewer behavior introduced in
  ``716aaaa58ad7bfaf34d2f771549d461204d1b4ba``).
- New ``dr`` module (``mjlab.envs.mdp.dr``) replacing ``randomize_field``
  with typed per-field domain randomization functions. Each function
  automatically recomputes derived fields via ``set_const``. Highlights:

  - Camera and light randomization: ``dr.cam_fovy``, ``dr.cam_pos``,
    ``dr.cam_quat``, ``dr.cam_intrinsic``, ``dr.light_pos``,
    ``dr.light_dir``. Camera and light names are now supported in
    ``SceneEntityCfg`` (``camera_names`` / ``light_names``).
  - ``dr.pseudo_inertia`` for physics-consistent randomization of
    ``body_mass``, ``body_ipos``, ``body_inertia``, and ``body_iquat``
    via the pseudo-inertia matrix parameterization (Rucker & Wensing
    2022). Replaces the removed ``dr.body_inertia`` /
    ``dr.body_iquat``.
  - ``dr.geom_size`` with automatic recomputation of ``geom_rbound``
    and ``geom_aabb`` for broadphase consistency.
  - ``dr.tendon_armature`` and ``dr.tendon_frictionloss``.
  - ``dr.body_quat``, ``dr.geom_quat``, and ``dr.site_quat`` with RPY
    perturbation composed onto the default quaternion.
  - Extensible ``Operation`` and ``Distribution`` types. Users can define
    custom operations and distributions as class instances and pass them
    anywhere a string is accepted. Built-in instances (``dr.abs``,
    ``dr.scale``, ``dr.add``, ``dr.uniform``, ``dr.log_uniform``,
    ``dr.gaussian``) are exported from the ``dr`` module.
  - ``dr.mat_rgba`` for per-world material color randomization. Tints
    the texture color, useful for randomizing appearance of textured
    surfaces. Material names are now supported in ``SceneEntityCfg``
    (``material_names``).
  - Fixed ``dr.effort_limits`` drifting on repeated randomization.
  - Fixed ``dr.body_com_offset`` not triggering ``set_const``.

- ``export-scene`` CLI script to export any task scene or asset_zoo entity
  (``g1``, ``go1``, ``yam``) to a directory or zip archive for inspection
  and debugging.

- ``yam_lift_cube_vision_env_cfg`` now randomizes cube color (``dr.geom_rgba``)
  on every reset when ``cam_type="rgb"``.

- The native viewer now reflects per-world DR changes to visual model fields
  on each reset. Geom appearance, body and site poses, camera parameters,
  and light positions are all synced from the GPU model before rendering.
  Inertia boxes (press ``I``) and camera frustums (press ``Q``) update
  correctly when the corresponding fields are randomized. See
  :doc:`randomization` for viewer-specific caveats.

- ``MaterialCfg.geom_names_expr`` for assigning materials to geoms by
  name pattern during ``edit_spec``.

- ``TerrainEntityCfg`` now exposes ``textures``, ``materials``, and
  ``lights`` as configurable fields (previously hardcoded). Set
  ``textures=()``, ``materials=()`` to use flat ``dr.geom_rgba``
  instead of the default checker texture.

- ``DebugVisualizer`` now supports ellipsoid visualization via
  ``add_ellipsoid``.

- Interactive velocity joystick sliders in the Viser viewer. Enable the
  joystick under Commands/Twist to override velocity commands with manual
  sliders for ``lin_vel_x``, ``lin_vel_y``, and ``ang_vel_z``
  (`#666 <https://github.com/mujocolab/mjlab/issues/666>`_).
- Per-term debug visualization toggles in the Viser viewer. Individual
  command term visualizers (e.g. velocity arrows) can now be toggled
  independently under Scene/Debug Viz.
- Viewer single-step mode: press RIGHT arrow (native) or click "Step"
  (Viser) to advance exactly one physics step while paused.
- Viewer error recovery: exceptions during stepping now pause the viewer
  and log the traceback instead of crashing the process.
- Native viewer runs forward kinematics while paused, keeping
  perturbation visuals accurate.
- Viewer speed multipliers use clean power-of-2 fractions (1/32x to 1x).

- Visualizers display the realtime factor alongside FPS.

- ``joint_torques_l2`` now respects ``SceneEntityCfg.actuator_ids``,
  allowing penalization of a subset of actuators instead of all of them
  (`#703 <https://github.com/mujocolab/mjlab/pull/703>`_). Contribution by
  `@saikishor <https://github.com/saikishor>`_.

- Terrain is now a proper ``Entity`` subclass (``TerrainEntity``). This
  allows domain randomization functions to target terrain parameters
  (friction, cameras, lights) via ``SceneEntityCfg("terrain", ...)``.
  ``TerrainImporter`` / ``TerrainImporterCfg`` remain as aliases but will be
  deprecated in a future version.
- Added ``upload_model`` option to ``RslRlBaseRunnerCfg`` to control W&B model
  file uploads (``.pt`` and ``.onnx``) while keeping metric logging enabled
  (`#654 <https://github.com/mujocolab/mjlab/pull/654>`_).
- ``Scene.write(output_dir, zip=False)`` exports the scene XML and mesh
  assets to a directory (or zip archive). Replaces ``Scene.to_zip()``.
- ``Entity.write_xml()`` and ``Scene.write()`` now apply XML fixups
  (empty defaults, duplicate nested defaults) and strip buffer textures
  that ``MjSpec.to_xml()`` cannot serialize.
- ``fix_spec_xml`` and ``strip_buffer_textures`` utilities in
  ``mjlab.utils.xml``.

Changed
^^^^^^^

- Native viewer now syncs ``xfrc_applied`` to the render buffer and draws
  arrows for any nonzero applied forces. Mouse perturbation forces are
  converted to ``qfrc_applied`` (generalized joint space) so they coexist
  with programmatic forces on ``xfrc_applied`` without conflict.
- ``ViewerConfig.OriginType.WORLD`` now configures a free camera at the
  specified lookat point instead of auto tracking a body. A new ``AUTO``
  origin type (now the default) preserves the previous auto tracking
  behavior.
- Upgraded ``rsl-rl-lib`` from 4.0.1 to 5.0.1. ``RslRlModelCfg`` now
  uses ``distribution_cfg`` dict instead of ``stochastic`` /
  ``init_noise_std`` / ``noise_std_type``. Existing checkpoints are
  automatically migrated on load.
- Reorganized the Viser Controls tab into a cleaner folder hierarchy:
  Info, Simulation, Commands, Scene (with Environment, Camera, Debug Viz,
  Contacts sub-folders), and Camera Feeds. The Environment folder is
  hidden for single-env tasks and the Commands folder is hidden when no
  command terms are active.
- Viser camera tracking is now enabled by default so the agent stays in
  frame on launch.
- Self collision and illegal contact sensors now use ``history_length`` to
  catch contacts across decimation substeps. Reward and termination functions
  read ``force_history`` with a configurable ``force_threshold``.
- Replaced the single ``scale`` parameter in ``DifferentialIKActionCfg`` with
  separate ``delta_pos_scale`` and ``delta_ori_scale`` for independent scaling
  of position and orientation components.
- Improved offscreen multi environment framing by selecting neighboring
  environments around the focused env instead of first N envs.
- Tuned tracking task viewer defaults for tighter camera framing.
- Disabled shadow casting on the G1 tracking light to avoid duplicate
  stacked shadows when robots are close.

Fixed
^^^^^

- Fixed actuator target resolution for entities whose ``spec_fn`` uses
  internal ``MjSpec.attach(prefix=...)``
  (`#709 <https://github.com/mujocolab/mjlab/issues/709>`_).
- Fixed viewer physics loop starving the renderer by replacing the single
  sim-time budget with a two-clock design (tracked vs actual sim time).
  Physics now self-corrects after overshooting, keeping FPS smooth at all
  speed multipliers.
- Bundled ``ffmpeg`` for ``mediapy`` via ``imageio-ffmpeg``, removing the
  requirement for a system ``ffmpeg`` install. Thanks to
  `@rdeits-bd <https://github.com/rdeits-bd>`_ for the suggestion.
- Fixed ``height_scan`` returning ~0 for missed rays; now defaults to
  ``max_distance``. Replaced ``clip=(-1, 1)`` with ``scale`` normalization
  in the velocity task config. Thanks to `@eufrizz <https://github.com/eufrizz>`_
  for reporting and the initial fix (`#642 <https://github.com/mujocolab/mjlab/pull/642>`_).
- Fixed ghost mesh visualization for fixed-base entities by extending
  ``DebugVisualizer.add_ghost_mesh`` to optionally accept ``mocap_pos`` and
  ``mocap_quat`` (`#645 <https://github.com/mujocolab/mjlab/pull/645>`_).
- Fixed viser viewer crashing on scenes with no mocap bodies by adding
  an ``nmocap`` guard, matching the native viewer behavior.
- Fixed offscreen rendering artifacts in large vectorized scenes by applying
  a render local extent override in ``OffscreenRenderer`` and restoring the
  original extent on close.
- Fixed ``RslRlVecEnvWrapper.unwrapped`` to return the base environment,
  ensuring checkpoint state restore and logging work correctly when wrappers
  such as ``VideoRecorder`` are enabled.

Version 1.1.1 (February 14, 2026)
---------------------------------

Added
^^^^^

- Added reward term visualization to the native viewer (toggle with ``P``) (`#629 <https://github.com/mujocolab/mjlab/pull/629>`_).
- Added ``DifferentialIKAction`` for task-space control via damped
  least-squares IK. Supports weighted position/orientation tracking,
  soft joint-limit avoidance, and null-space posture regularization.
  Includes an interactive viser demo (``scripts/demos/differential_ik.py``) (`#632 <https://github.com/mujocolab/mjlab/pull/632>`_).

Fixed
^^^^^

- Fixed ``play.py`` defaulting to the base rsl-rl ``OnPolicyRunner`` instead
  of ``MjlabOnPolicyRunner``, which caused a ``TypeError`` from an unexpected
  ``cnn_cfg`` keyword argument (`#626 <https://github.com/mujocolab/mjlab/pull/626>`_). Contribution by
  `@griffinaddison <https://github.com/griffinaddison>`_.

Changed
^^^^^^^

- Removed ``body_mass``, ``body_inertia``, ``body_pos``, and ``body_quat``
  from ``FIELD_SPECS`` in domain randomization. These fields have derived
  quantities that require ``set_const`` to recompute; without that call,
  randomizing them silently breaks physics (`#631 <https://github.com/mujocolab/mjlab/pull/631>`_).
- Replaced ``moviepy`` with ``mediapy`` for video recording. ``mediapy``
  handles cloud storage paths (GCS, S3) natively (`#637 <https://github.com/mujocolab/mjlab/pull/637>`_).

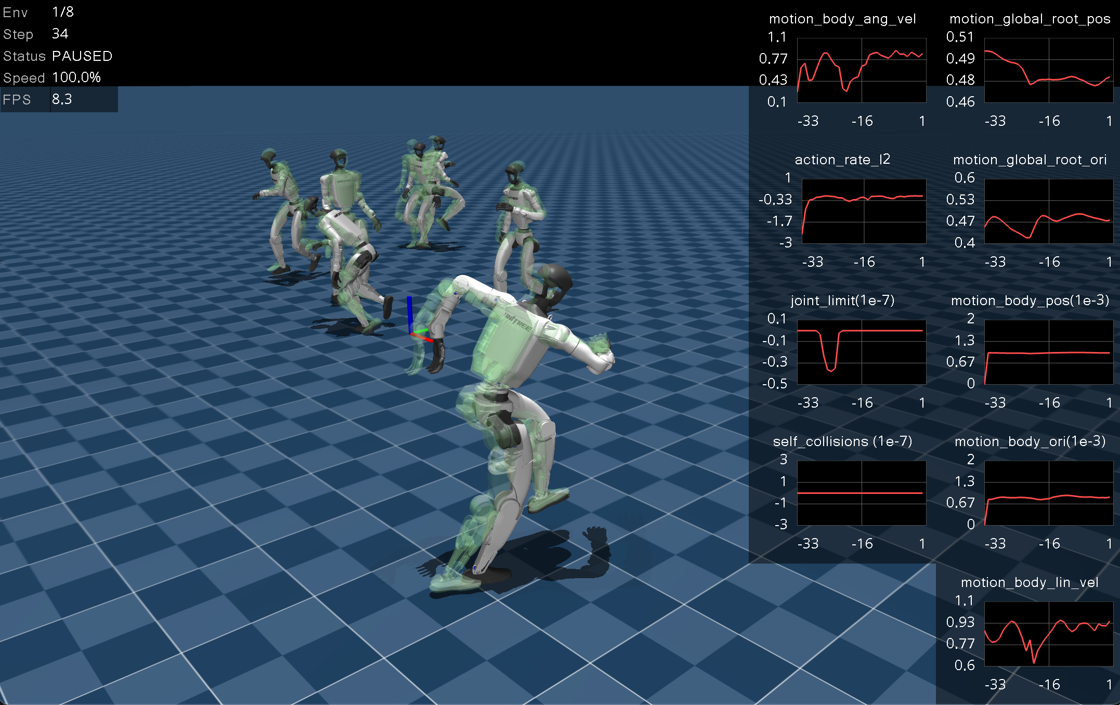
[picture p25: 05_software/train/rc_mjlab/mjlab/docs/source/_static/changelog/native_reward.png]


Version 1.1.0 (February 12, 2026)
---------------------------------

Added
^^^^^

- Added RGB and depth camera sensors and BVH-accelerated raycasting (`#597 <https://github.com/mujocolab/mjlab/pull/597>`_).
- Added ``MetricsManager`` for logging custom metrics during training (`#596 <https://github.com/mujocolab/mjlab/pull/596>`_).
- Added terrain visualizer (`#609 <https://github.com/mujocolab/mjlab/pull/609>`_). Contribution by
  `@mktk1117 <https://github.com/mktk1117>`_.

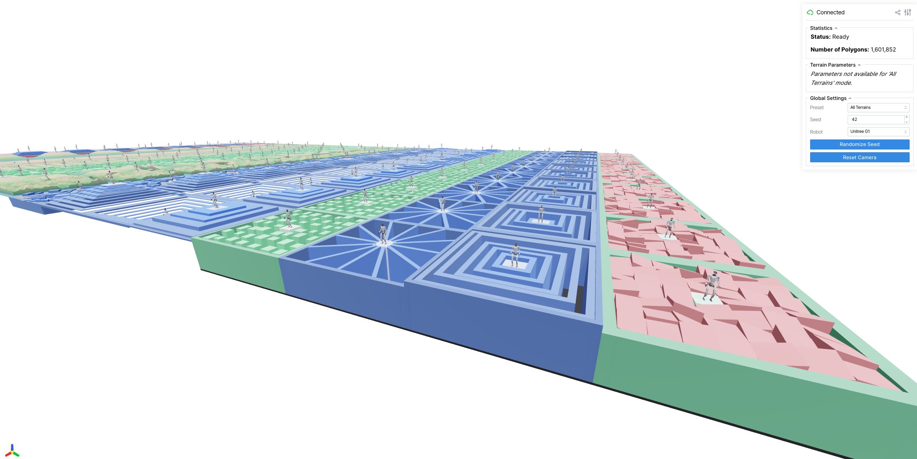
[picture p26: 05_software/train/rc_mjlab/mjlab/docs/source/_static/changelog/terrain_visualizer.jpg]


- Added many new terrains including ``HfDiscreteObstaclesTerrainCfg``,
  ``HfPerlinNoiseTerrainCfg``, ``BoxSteppingStonesTerrainCfg``,
  ``BoxNarrowBeamsTerrainCfg``, ``BoxRandomStairsTerrainCfg``, and
  more. Added flat patch sampling for heightfield terrains (`#542 <https://github.com/mujocolab/mjlab/pull/542>`_, `#581 <https://github.com/mujocolab/mjlab/pull/581>`_).
- Added site group visualization to the Viser viewer (Geoms and Sites
  tabs unified into a single Groups tab) (`#551 <https://github.com/mujocolab/mjlab/pull/551>`_).
- Added ``env_ids`` parameter to ``Entity.write_ctrl_to_sim`` (`#567 <https://github.com/mujocolab/mjlab/pull/567>`_).

Changed
^^^^^^^

- Upgraded ``rsl-rl-lib`` to 4.0.0 and replaced the custom ONNX
  exporter with rsl-rl's built-in ``as_onnx()`` (`#589 <https://github.com/mujocolab/mjlab/pull/589>`_, `#595 <https://github.com/mujocolab/mjlab/pull/595>`_).
- ``sim.forward()`` is now called unconditionally after the decimation
  loop. See :ref:`faq-sim-forward` for details (`#591 <https://github.com/mujocolab/mjlab/pull/591>`_).
- Unnamed freejoints are now automatically named to prevent
  ``KeyError`` during entity init (`#545 <https://github.com/mujocolab/mjlab/pull/545>`_).

Fixed
^^^^^

- Fixed ``randomize_pd_gains`` crash with ``num_envs > 1`` (`#564 <https://github.com/mujocolab/mjlab/pull/564>`_).
- Fixed ``ctrl_ids`` index error with multiple actuated entities (`#573 <https://github.com/mujocolab/mjlab/pull/573>`_).
  Reported by `@bwrooney82 <https://github.com/bwrooney82>`_.
- Fixed Viser viewer rendering textured robots as gray (`#544 <https://github.com/mujocolab/mjlab/pull/544>`_).
- Fixed Viser plane rendering ignoring MuJoCo size parameter (`#540 <https://github.com/mujocolab/mjlab/pull/540>`_).
- Fixed ``HfDiscreteObstaclesTerrainCfg`` spawn height (`#552 <https://github.com/mujocolab/mjlab/pull/552>`_).
- Fixed ``RaycastSensor`` visualization ignoring the all-envs toggle (`#607 <https://github.com/mujocolab/mjlab/pull/607>`_).
  Contribution by `@oxkitsune <https://github.com/oxkitsune>`_.

Version 1.0.0 (January 28, 2026)
--------------------------------

Initial release of mjlab.

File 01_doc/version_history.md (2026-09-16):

# 版本演进

本项目使用里程碑 Tag 保存时间演进；同一架构的小步迭代不复制目录。ROS 2 的无后缀、`_v2`、`_v3` 目录分别代表三个架构大版本，并在 `v1.1.0` 中同时保留。

| Tag | 阶段 | 核心内容 |
| --- | --- | --- |
| `v0.1.0` | 8DOF 中期检查 | 8DOF 串联足机械与大疆 A 板实机版本 |
| `v0.2.0` | 16DOF 机械 | 16DOF 串联轮足机械 CAD 与 STEP |
| `v0.3.0` | 第一代软件闭环 | 早期训练、MJCF、MuJoCo、Sim2Sim、IK 与 Python Sim2Real |
| `v0.3.1` | 实机记录 | 补充第一代 Sim2Real 实机视频 |
| `v0.4.0` | 新训练基线 | 第一份完整的新 MJCF、新 mjlab 框架和 Rough 策略工程 |
| `v0.5.0` | 随机化增强 | 扩大观测、延迟和动力学随机化，加入持续外力扰动 |
| `v0.6.0` | 比赛训练架构 | 分轴奖励、自适应指令课程、障碍释放课程和比赛站姿 |
| `v0.7.0` | MuJoCo 工具 | 姿态优化、IK 扫描、动力学、MPC 和 GUI 调试工具 |
| `v0.8.0` | 后期 Sim2Sim | ONNX 回放、IK/路线检查工具和比赛最终 Rough 策略 |
| `v0.8.1` | 导航打点工具 | 地图/航点编辑、路线迭代和抽样 PCD 补充包 |
| `v0.9.0` | Python Sim2Real v2 | 反馈新鲜度、Odin odom 诊断、Web 调试和安全监控增强 |
| `v0.10.0` | ROS 2/C++ 初版 | 50 Hz C++ 推理、200 Hz CAN 热路径和 ROS 2 系统集成 |
| `v0.11.0` | ROS 2 导航原型 | 简单导航、PCD 交互定位、任务点和 Web 导航调试 |
| `v0.11.1` | Odin 与站姿调参 | 完整 Odin 驱动、TensorRT、多策略切换和调参站姿 |
| `v0.12.0` | 里程计导航联调 | 纯里程计 fallback、A_min 路线、TF 冲突保护和 model_9600 |
| `v1.0.0` | 比赛最终部署初次归档 | last_not_slalom_1050、model_6800/model_84、最终路线和触控屏；当时暂存于无后缀目录 |
| `v1.0.1` | 比赛成果媒体补充 | 最终机器人图片与 1050 分比赛视频 |
| `v1.0.2` | 文档一致性修正 | 统一历史 Tag、当前快照和成果媒体的描述 |
| `v1.1.0` | 三代目录规范化 | 恢复无后缀初版、保留 v2 里程计版、明确最终比赛 v3，并校准训练 README |

> 原先临时归档为 `v0.9.0` 的最终 ROS 2/C++ 比赛部署已保存在 `backup/final-ros2-v0.9.0` 分支和 `backup-v0.9.0-ros2-final` 标签中，重排后已正式归入 `v1.0.0`。

## `v0.9.0` 的 Python Sim2Real v2

- 归档 `real/sim2real_v2` 真机部署版本，保持 `53D -> 16D` 策略观测和动作契约。
- 增加电机反馈新鲜度判断、Odin odom 诊断、命令限加速度平滑和 Web 运行时诊断。
- 保留 Python 策略运行时、ONNX/PT 模型、MJCF、Odin 接口、Web 工具和安全保护链路。
- 排除运行日志、测试日志、临时 XML 和开发交接草稿；后续 ROS 2/C++ 版本另行归档。

## `v0.10.0` 的 ROS 2/C++ Sim2Real 初版

- 归档 `real/sim2real_ros2`，将 Python 部署契约迁移到 ROS 2 Humble 与 C++ 运行时。
- 保留 53D 观测、16D 动作、50 Hz 策略循环和 200 Hz SocketCAN 电机热路径。
- 增加消息接口、硬件桥、策略运行时、命令仲裁、Nav2 配置、Docker 和 Windows Web 调试工具。
- 原始快照中的 `src/odin_ros_driver` 为空目录，因此本版本仍需外部 Odin 驱动，不能宣称传感器依赖已自包含。
- 保留原始候选 ONNX 文件以记录初版部署试验；排除计划、任务和 walkthrough 草稿。

## `v0.11.0` 的 ROS 2 Sim2Real v2

- 归档 `real/sim2real_ros2_v2`，保持 `v0.10.0` 的 ROS 2/C++ 控制契约。
- 增加 `simple_nav_node.py`、PCD 点击工具、任务点/任务序列配置和 Web 导航控制入口。
- 默认命令源从遥控切换为 `NAV`，加入简单导航状态、PCD 位姿和地图显示链路。
- 原始 `map1.pcd`、`map6.pcd` 分别约 49.05 MiB、44.24 MiB，归档时确定性抽样到 10 MB 以下并记录哈希。
- 原始快照中的 Odin 驱动仍为空目录；排除设备运行日志和开发草稿。

## `v0.11.1` 的 Odin、TensorRT 与站姿调参

- 归档 `real/sim2real_ros2_v2(z=0.380 hip=0.670 knee=-1.390)`，在同一 `sim2real_ros2_v2` 目录中记录真实差异。
- 首次随部署工程保留完整 Odin ROS 驱动、Apache-2.0 许可证、设备标定参数和预编译 SDK 静态库。
- 策略运行时增加 TensorRT、ONNX 回退、Rough/Crawl 模式切换、事件日志和更完整的电机失效诊断。
- 默认 Rough 策略为 `NEWmodel_1900`，默认站姿为髋俯仰 `0.670`、膝关节 `-1.390`；Crawl 配置使用 IK 后端。
- `map_b.pcd` 从 1,080,047 点确定性抽样为 270,012 点，并保留原始和抽样哈希。
- 排除嵌套 Git、Odin 运行日志、缓存、开发草稿和未被配置引用的候选策略。

## `v0.12.0` 的里程计导航联调

- 归档 `real/sim2real_ros2_v2(odom)`，继续沿用 `sim2real_ros2_v2` 目录的线性演进。
- 将 Rough 策略切换为 `model_9600`，默认站姿恢复为髋俯仰 `0.550`、膝关节 `-1.125`。
- Odin `custom_map_mode` 固定为纯里程计，加入 odom 新鲜度、外部 map/odom TF 冲突和任务结束交接保护。
- 增加 A_min 路线、PCD 地图编辑工具和三份抽样点云；原始大 PCD 不直接进入 Git。
- 保留完整 Odin 驱动、标定参数和 SDK 静态库；未找到的 `map_a.bin` 仍不伪造，重定位闭环不在本 Tag 声称已复现。

## `v1.0.0` 的比赛最终部署

- 首次归档原始 `sim2real_ros2_v2(last_not_slalom_1050)` 最终 ROS 2/C++ 真机工程；该 Tag 中暂存于无后缀 `real/sim2real_ros2`，目录命名在 `v1.1.0` 才修正为 `real/sim2real_ros2_v3`。`1050` 是比赛成绩，不是模型编号。
- Rough 使用 `model_6800`，Wall 使用 `model_84`，Crawl 按比赛配置使用 IK 后端。
- 保留最终五份路线、1 号场地抽样 PCD、Odin 驱动、CAN 硬件桥、命令仲裁、导航和 Orin 触控屏 UI。
- 最终配置默认命令源为 `NAV`、定位模式为 `relocal`，但真实 Odin `1hao.bin` 不在备份中，重定位闭环需要从比赛设备补回。
- 排除嵌套 Git、日志、备份、候选策略、构建产物和开发草稿；TensorRT engine 仅代表比赛机环境。

## `v1.0.1` 的比赛成果媒体补充

- 保持 `v1.0.0` 的比赛最终代码和部署内容不变。
- 补充最终机器人图片和比赛视频，成绩为 1050 分、第七名（前 5%）。
- 代码复现可查看 `v1.0.0`，包含成果媒体的对应快照可查看 `v1.0.1`。

## `v1.0.2` 的文档一致性修正

- 统一 ROS 2 历史 Tag、当前工作树和媒体补丁的说明。
- 该版本仅修正文档，没有改变训练或真机运行代码。

## `v1.1.0` 的目录与说明规范化

- 从 `v0.10.0` 恢复无后缀 `sim2real_ros2` 初版快照。
- `sim2real_ros2_v2` 保持 `v0.12.0` 里程计联调快照。
- 将 `last_not_slalom_1050` 最终比赛部署正式命名为 `sim2real_ros2_v3`。
- 依据当前源码重新校准 `rc_mjlab` README 中的物理步长、控制频率、环境数、执行器、地形、奖励和随机化说明。

## `v0.4.0` 的模型变化

- 机械 CAD 不变。
- MJCF 更新整机质量和惯性参数，旧、新 `wheelleg.xml` 的 SHA-256 不同。
- mjlab 上游基准从 `00409797` 更新到 `40f8d93e`。
- 保留轮腿分组执行器随机化所需的本地补丁。
- 本阶段归档 `model_rough.pt`，不将生成日志、缓存和临时 XML 纳入版本库。

## `v0.5.0` 的训练变化

- MJCF、mjlab 基准和已有模型文件保持不变。
- 投影重力噪声由 `±0.05` 扩大到 `±0.08`。
- 腿与轮动作的最大随机延迟由 2 步增加到 4 步。
- 地面摩擦随机范围由 `0.3–1.0` 扩大到 `0.15–1.25`。
- 执行器刚度和阻尼缩放由 `0.9–1.1` 扩大到 `0.5–1.5`。
- 增加膝部和轮部质量的 `0.7–1.3` 随机缩放。
- 增加作用于机身的连续随机外力和力矩扰动。

## `v0.6.0` 的比赛训练架构

- 保持 `v0.4.0` 引入的新 MJCF 和 mjlab 框架不变。
- 将线速度奖励拆分为 x/y 两轴，并独立配置偏航角速度奖励。
- 增加自适应 x/y/yaw 指令范围课程。
- 增加障碍地形逐步释放与更严格的地形晋级逻辑。
- 增加楼梯横向速度和偏航漂移约束。
- 默认站姿调整为髋俯仰 `0.550`、膝关节 `-1.125`，初始机身高度为 `0.42 m`。
- 增加速度误差、轮速跟踪、动作和姿态等训练诊断指标。
- 该 Tag 保存比赛训练代码架构，不把每次继续训练产生的 checkpoint 误记为新的软件版本。

训练阶段的详细关系见 [`training_evolution.md`](training_evolution.md)。

## `v0.7.0` 的独立 MuJoCo 工具

- 比赛训练架构、MJCF、模型和依赖锁文件保持 `v0.6.0` 状态不变。
- 增加解析姿态表、RL 友好姿态筛选和 MuJoCo 静态姿态优化。
- 增加 IK/差速轮参数扫描，可导出 JSON 结果。
- 增加 Robot、Controller、Dynamics、MPCController 和 GUI 调试链路。
- 记录历史工具常量与新版 MJCF 质量、比赛默认站姿之间的参数边界，避免将分析结果直接当作已校准真机参数。

## `v0.8.0` 的后期 Sim2Sim

- 比赛训练任务、MJCF 和 `v0.7.0` 的 MuJoCo 工具保持不变。
- 策略运行器增加 ONNX 加载，并允许在缺少 `pynput` 时关闭后台键盘监听继续运行。
- MuJoCo 执行器重建同时兼容新旧 Spec 删除接口。
- 增加 PT→ONNX 导出、IK 补偿扫描、纯 IK 绕桩和 ONNX 批量路线检查入口。
- 归档比赛最终 Rough 策略 `model_6800.onnx`；其 SHA-256 为 `3C994BDD3434AD15770A52AC0E8D229F502F00D6511CDD42C2E2C742301AEF13`。
- Crawl 权重、运行日志、临时 XML 和大量重复路线实验不在本阶段归档。

## `v0.8.1` 的导航打点工具

- 补充 Pygame 地图/PCD/航点综合编辑器、避障区域编辑器和坐标变换工具。
- 补充路线安全检查、候选航点优化、XML/航点镜像和批量 Sim2Sim 实验入口。
- 按源文件时间保留 14 份比赛路线 JSON，不将开发期文件名误解释为正式版本号。
- 补充 `1hao.xml`、`2hao.xml`、`A_C.xml`，并为 `1B_FF.json` 补齐其引用的 `B_C.xml`。
- 将两份约 915 MiB 的原始 ASCII PCD 确定性抽样为各小于 10 MB 的预览点云；抽样参数、点数和哈希记录在工具 README。
- 训练代码、MJCF、比赛策略和历史依赖锁保持 `v0.8.0` 状态不变。

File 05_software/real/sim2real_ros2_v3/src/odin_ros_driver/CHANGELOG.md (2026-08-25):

v0.11.0 2026_0618
Required Minimum Firmware Version：0.12.0
1.Reduce cloud slam latency
2.Improve get mapping result 

v0.10.5 2026_0525
1.modify recorddata format，add device_id、algorithm_version key
2.fix download map fail when in slam mode(USB2.0)
3.fix upload map fail when in relocalization mode(USB2.0)

v0.10.4 2026_0522
1.fix usb2.0 heartBeat timeout to cause soft detaching
2.add custom_init_pose_search_radius and custom_init_pose_max_rot_deg in control_command.yaml

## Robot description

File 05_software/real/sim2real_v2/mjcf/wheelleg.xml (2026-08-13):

<mujoco model="wheelleg">
  <compiler angle="radian" meshdir="meshes/"/>

  <default>
    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
  </default>
  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

  <worldbody>
    <body name="base_link">
      <inertial pos="0.1517 0.0002 0.0542" mass="3.5" diaginertia="0.0215 0.0904 0.0985"/>
      <joint type="free"/>
      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
      <body name="fl_hip_abduction_Link" pos="0.32826 0.066172 0.053981">
        <inertial pos="0.0488 -0.0026 0.0007" mass="0.5" diaginertia="0.0003 0.0006 0.0005"/>
        <joint name="fl_hip_abduction_joint" pos="0 0 0" axis="1 0 0" range="-0.436 0.611" actuatorfrcrange="-17 17" damping="0.01" frictionloss="0.01" armature="0.0042"/>
        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
        <body name="fl_hip_pitch_Link" pos="0.06389 -0.027344 0.00010727" quat="0.999997 -0.0025023 0 0">
          <inertial pos="0.0019 0.1119 -0.048" mass="0.935" diaginertia="0.0062 0.0064 0.001"/>
          <joint name="fl_hip_pitch_joint" pos="0 0 0" axis="0 1 0" range="-2.58 2.58" actuatorfrcrange="-17 17" damping="0.01" frictionloss="0.01" armature="0.0042"/>
          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
          <body name="fl_knee_Link" pos="0 0.1035 -0.25" quat="0.999997 0.0025023 0 0">
            <inertial pos="0.0002 0.0242 -0.1539" mass="0.651" fullinertia="0.0042 0.0045 0.0005 0 0 0.0002"/>
            <joint name="fl_knee_joint" pos="0 0 0" axis="0 1 0" range="-2.65 2.65" actuatorfrcrange="-17 17" damping="0.01" frictionloss="0.01" armature="0.0042"/>
            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
            <body name="fl_wheel_Link" pos="0 0.014699 -0.20011">
              <inertial pos="-0.0002 0.0407 -0.0001" mass="0.53" diaginertia="0.0017 0.0032 0.0017"/>
              <joint name="fl_wheel_joint" pos="0 0 0" axis="0 1 0" actuatorfrcrange="-17 17" damping="0.01" frictionloss="0.01" armature="0.0042"/>
              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
            </body>
          </body>
        </body>
      </body>
      <body name="fr_hip_abduction_Link" pos="0.32826 -0.065853 0.054034">
        <inertial pos="0.0488 0.0026 0.0008" mass="0.5" diaginertia="0.0003 0.0006 0.0005"/>
        <joint name="fr_hip_abduction_joint" pos="0 0 0" axis="1 0 0" range="-0.611 0.436" actuatorfrcrange="-17 17" damping="0.01" frictionloss="0.01" armature="0.0042"/>
        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
        <body name="fr_hip_pitch_Link" pos="0.06389 0.027311 -0.00036027" quat="0.999976 -0.00686995 0 0">
          <inertial pos="-0.0019 -0.1119 -0.048" mass="0.935" diaginertia="0.0062 0.0064 0.001"/>
          <joint name="fr_hip_pitch_joint" pos="0 0 0" axis="0 1 0" range="-2.58 2.58" actuatorfrcrange="-17 17" damping="0.01" frictionloss="0.01" armature="0.0042"/>
          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
          <body name="fr_knee_Link" pos="-0.00075079 -0.1035 -0.25" quat="0.999976 0.00686995 0 0">
            <inertial pos="-0.0002 -0.0242 -0.1539" mass="0.651" fullinertia="0.0042 0.0045 0.0005 0 0 0.0001"/>
            <joint name="fr_knee_joint" pos="0 0 0" axis="0 1 0" range="-2.65 2.65" actuatorfrcrange="-17 17" damping="0.01" frictionloss="0.01" armature="0.0042"/>
            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
            <body name="fr_wheel_Link" pos="0 -0.018447 -0.1998">
              <inertial pos="0.0002 -0.0407 -0.0001" mass="0.53" diaginertia="0.0017 0.0032 0.0017"/>
              <joint name="fr_wheel_joint" pos="0 0 0" axis="0 1 0" actuatorfrcrange="-17 17" damping="0.01" frictionloss="0.01" armature="0.0042"/>
              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
            </body>
          </body>
        </body>
      </body>
      <body name="rl_hip_abduction_Link" pos="-0.024743 0.066141 0.054034">
        <inertial pos="-0.0488 -0.0026 -0.0008" mass="0.5" diaginertia="0.0003 0.0006 0.0005"/>
        <joint name="rl_hip_abduction_joint" pos="0 0 0" axis="1 0 0" range="-0.436 0.611" actuatorfrcrange="-17 17" damping="0.01" frictionloss="0.01" armature="0.0042"/>
        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
        <body name="rl_hip_pitch_Link" pos="-0.06389 -0.027309 0.00045509">
          <inertial pos="0.0019 0.1119 -0.048" mass="0.935" diaginertia="0.0062 0.0064 0.001"/>
          <joint name="rl_hip_pitch_joint" pos="0 0 0" axis="0 1 0" range="-2.58 2.58" actuatorfrcrange="-17 17" damping="0.01" frictionloss="0.01" armature="0.0042"/>
          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
          <body name="rl_knee_Link" pos="0 0.099459 -0.25163">
            <inertial pos="0.0002 0.0242 -0.1539" mass="0.651" fullinertia="0.0042 0.0045 0.0005 0 0 -0.0003"/>
            <joint name="rl_knee_joint" pos="0 0 0" axis="0 1 0" range="-2.65 2.65" actuatorfrcrange="-17 17" damping="0.01" frictionloss="0.01" armature="0.0042"/>
            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
            <body name="rl_wheel_Link" pos="0 0.012475 -0.20027">
              <inertial pos="-0.0002 0.0407 -0.0001" mass="0.53" diaginertia="0.0017 0.0032 0.0017"/>
              <joint name="rl_wheel_joint" pos="0 0 0" axis="0 1 0" actuatorfrcrange="-17 17" damping="0.01" frictionloss="0.01" armature="0.0042"/>
              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
            </body>
          </body>
        </body>
      </body>
      <body name="rr_hip_abduction_Link" pos="-0.024743 -0.065884 0.053981">
        <inertial pos="-0.0488 0.0026 0.0008" mass="0.5" diaginertia="0.0003 0.0006 0.0005"/>
        <joint name="rr_hip_abduction_joint" pos="0 0 0" axis="1 0 0" range="-0.611 0.436" actuatorfrcrange="-17 17" damping="0.01" frictionloss="0.01" armature="0.0042"/>
        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
        <body name="rr_hip_pitch_Link" pos="-0.06389 0.027341 0.00041625">
          <inertial pos="-0.002 -0.1111 -0.0498" mass="0.935" diaginertia="0.0062 0.0064 0.001"/>
          <joint name="rr_hip_pitch_joint" pos="0 0 0" axis="0 1 0" range="-2.58 2.58" actuatorfrcrange="-17 17" damping="0.01" frictionloss="0.01" armature="0.0042"/>
          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
          <body name="rr_knee_Link" pos="-0.00075079 -0.099408 -0.25165">
            <inertial pos="-0.0002 -0.0225 -0.1541" mass="0.651" fullinertia="0.0042 0.0045 0.0005 0 0 -0.0001"/>
            <joint name="rr_knee_joint" pos="0 0 0" axis="0 1 0" range="-2.65 2.65" actuatorfrcrange="-17 17" damping="0.01" frictionloss="0.01" armature="0.0042"/>
            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
            <body name="rr_wheel_Link" pos="0 -0.012435 -0.20027">
              <inertial pos="0.0002 -0.0407 -0.0005" mass="0.53" diaginertia="0.0017 0.0032 0.0017"/>
              <joint name="rr_wheel_joint" pos="0 0 0" axis="0 1 0" actuatorfrcrange="-17 17" damping="0.01" frictionloss="0.01" armature="0.0042"/>
              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
            </body>
          </body>
        </body>
      </body>
      <body name="imu_link" pos="0.1518 0 0.127">
        <inertial pos="0 0 0" mass="0" diaginertia="0 0 0"/>
      </body>
    </body>
  </worldbody>
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

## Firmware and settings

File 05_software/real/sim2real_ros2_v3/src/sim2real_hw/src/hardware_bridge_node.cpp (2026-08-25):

#include "sim2real_hw/hardware_bridge_node.hpp"

#include <algorithm>
#include <chrono>
#include <cmath>
#include <cctype>
#include <cstring>
#include <sstream>
#include <string>
#include <thread>

#include <sys/ioctl.h>
#include <sys/socket.h>
#include <linux/can.h>
#include <linux/can/raw.h>
#include <net/if.h>
#include <unistd.h>
#include <fcntl.h>
#include <errno.h>

#include "rclcpp/executors/multi_threaded_executor.hpp"
#include "sim2real_common/deployment_contract.hpp"

using namespace std::chrono_literals;

namespace sim2real_hw
{

// Protocol constants
const std::uint32_t COMM_ENABLE = 3;
const std::uint32_t COMM_DISABLE = 4;
const std::uint32_t COMM_WRITE_PARAMETER = 18;
const std::uint32_t COMM_READ_PARAMETER = 17;
const std::uint32_t COMM_OPERATION_CONTROL = 1;
const std::uint32_t COMM_SET_ZERO_POSITION = 6;
const std::uint16_t PARAM_MODE = 0x7005;
const std::uint16_t PARAM_VELOCITY_LIMIT = 0x7017;
const std::uint16_t PARAM_TORQUE_LIMIT = 0x700B;
const std::uint16_t PARAM_CAN_TIMEOUT = 0x7028;
const std::uint16_t PARAM_VBUS = 0x3007;
const std::uint16_t PARAM_DRV_FAULT = 0x3022;
const std::uint16_t PARAM_DRV_FAULT_DETAIL_1 = 0x3024;
const std::uint16_t PARAM_DRV_FAULT_DETAIL_2 = 0x3025;
const std::uint8_t HOST_ID = 0xFD;
constexpr int kMotorInitRetrySleepMs = 15;
constexpr int kMotorInitConfirmTimeoutMs = 120;
constexpr int kMotorRecoveryCooldownMs = 500;
constexpr std::uint32_t kMotorRecoveryTriggerStaleCount = 10;
constexpr std::uint32_t kMotorRecoveryAttemptLimit = 3;
inline void pack_u16_be(std::uint8_t* buf, std::uint16_t val)
{
  buf[0] = (val >> 8) & 0xFF;
  buf[1] = val & 0xFF;
}

inline float nearest_periodic(float val, float ref)
{
  float diff = val - ref;
  float wrapped = diff - 2.0f * static_cast<float>(M_PI) * std::floor((diff + static_cast<float>(M_PI)) / (2.0f * static_cast<float>(M_PI)));
  return ref + wrapped;
}

std::string extractJsonStringField(const std::string & payload, const std::string & key)
{
  const std::string needle = "\"" + key + "\":\"";
  const std::size_t start = payload.find(needle);
  if (start == std::string::npos) {
    return {};
  }

  const std::size_t value_start = start + needle.size();
  const std::size_t value_end = payload.find('"', value_start);
  if (value_end == std::string::npos) {
    return {};
  }

  return payload.substr(value_start, value_end - value_start);
}

std::string toLowerCopy(std::string value)
{
  std::transform(value.begin(), value.end(), value.begin(), [](unsigned char c) {
    return static_cast<char>(std::tolower(c));
  });
  return value;
}

HardwareBridgeNode::HardwareBridgeNode()
: Node("sim2real_hw_node")
{
  // 1. Declare and get parameters
  const std::string event_log_dir = declare_parameter<std::string>(
    "event_log_dir", "logs_v2_web");
  run_log_dir_ = event_log_dir;
  event_logger_.configure(event_log_dir, "sim2real_hw_events");
  target_timeout_ms_ = declare_parameter<double>("target_timeout_ms", 150.0);
  can0_name_ = declare_parameter<std::string>("can0_name", "can0");
  can1_name_ = declare_parameter<std::string>("can1_name", "can1");
  dry_run_ = declare_parameter<bool>("dry_run", true); // Default to dry-run for safety
  const std::vector<double> default_rough_pose(
    sim2real_common::DeploymentContract::kDefaultDofPos.begin(),
    sim2real_common::DeploymentContract::kDefaultDofPos.end());
  const std::vector<double> configured_rough_pose = declare_parameter<std::vector<double>>(
    "rough_default_dof_pos", default_rough_pose);
  if (configured_rough_pose.size() == rough_default_dof_pos_.size()) {
    for (std::size_t i = 0; i < rough_default_dof_pos_.size(); ++i) {
      rough_default_dof_pos_[i] = static_cast<float>(configured_rough_pose[i]);
    }
  } else {
    rough_default_dof_pos_ = sim2real_common::DeploymentContract::kDefaultDofPos;
    RCLCPP_WARN(
      get_logger(),
      "Parameter rough_default_dof_pos has %zu entries, expected 16. Falling back to deployment default pose.",
      configured_rough_pose.size());
  }
  active_default_dof_pos_ = rough_default_dof_pos_;
  const std::vector<double> default_crawl_pose = declare_parameter<std::vector<double>>(
    "crawl_default_dof_pos",
    std::vector<double>{
      0.2, 1.697, -2.650,
      -0.2, 1.697, -2.650,
      0.2, 1.697, -2.650,
      -0.2, 1.697, -2.650,
      0.0, 0.0, 0.0, 0.0
    });
  if (default_crawl_pose.size() == crawl_default_dof_pos_.size()) {
    for (std::size_t i = 0; i < crawl_default_dof_pos_.size(); ++i) {
      crawl_default_dof_pos_[i] = static_cast<float>(default_crawl_pose[i]);
    }
  } else {
    crawl_default_dof_pos_ = {
      0.2f, 1.697f, -2.650f,
      -0.2f, 1.697f, -2.650f,
      0.2f, 1.697f, -2.650f,
      -0.2f, 1.697f, -2.650f,
      0.0f, 0.0f, 0.0f, 0.0f
    };
    RCLCPP_WARN(
      get_logger(),
      "Parameter crawl_default_dof_pos has %zu entries, expected 16. Falling back to configured crawl pose.",
      default_crawl_pose.size());
  }
  const std::vector<double> default_wall_pose_param(
    rough_default_dof_pos_.begin(), rough_default_dof_pos_.end());
  const std::vector<double> default_wall_pose = declare_parameter<std::vector<double>>(
    "wall_default_dof_pos", default_wall_pose_param);
  if (default_wall_pose.size() == wall_default_dof_pos_.size()) {
    for (std::size_t i = 0; i < wall_default_dof_pos_.size(); ++i) {
      wall_default_dof_pos_[i] = static_cast<float>(default_wall_pose[i]);
    }
  } else {
    wall_default_dof_pos_ = rough_default_dof_pos_;
    RCLCPP_WARN(
      get_logger(),
      "Parameter wall_default_dof_pos has %zu entries, expected 16. Falling back to rough default pose.",
      default_wall_pose.size());
  }

  // Safety parameters
  safety_enabled_ = declare_parameter<bool>("safety_enabled", true);
  double max_target_offset = declare_parameter<double>("max_target_offset", 0.6);
  double model_switch_max_target_offset = declare_parameter<double>(
    "model_switch_max_target_offset", std::max(max_target_offset, 1.8));
  double hard_target_offset = declare_parameter<double>("hard_target_offset", 1.2);
  double max_ang_vel = declare_parameter<double>("max_ang_vel", 10.0);
  double max_tilt_z = declare_parameter<double>("max_tilt_z", -0.3);
  int clip_to_brake = declare_parameter<int>("clip_to_brake", 0);
  double imu_age_warn_ms = declare_parameter<double>("imu_age_warn_ms", 60.0);
  double imu_age_stop_ms = declare_parameter<double>("imu_age_stop_ms", 200.0);
  motor_temp_warn_c_ = static_cast<float>(declare_parameter<double>("motor_temp_warn_c", 100.0));
  motor_temp_fault_c_ = static_cast<float>(declare_parameter<double>("motor_temp_fault_c", 135.0));
  motor_bus_overvoltage_v_ = static_cast<float>(declare_parameter<double>("motor_bus_overvoltage_v", 60.0));
  motor_bus_undervoltage_v_ = static_cast<float>(declare_parameter<double>("motor_bus_undervoltage_v", 12.0));
  motor_current_warn_arms_ = static_cast<float>(declare_parameter<double>("motor_current_warn_arms", 10.5));
  motor_current_peak_arms_ = static_cast<float>(declare_parameter<double>("motor_current_peak_arms", 14.0));
  motor_torque_warn_nm_ = static_cast<float>(declare_parameter<double>("motor_torque_warn_nm", 13.0));
  motor_torque_peak_nm_ = static_cast<float>(declare_parameter<double>("motor_torque_peak_nm", 17.0));
  diag_poll_period_s_ = declare_parameter<double>("motor_diag_poll_period_s", 0.10);
  wheel_no_effect_command_threshold_ = static_cast<float>(
    declare_parameter<double>("wheel_no_effect_command_threshold", 1.0));
  wheel_no_effect_min_response_ratio_ = static_cast<float>(
    declare_parameter<double>("wheel_no_effect_min_response_ratio", 0.20));
  wheel_no_effect_velocity_epsilon_ = static_cast<float>(
    declare_parameter<double>("wheel_no_effect_velocity_epsilon", 0.25));
  wheel_no_effect_max_temperature_c_ = static_cast<float>(
    declare_parameter<double>("wheel_no_effect_max_temperature_c", 90.0));
  wheel_no_effect_min_bus_voltage_v_ = static_cast<float>(
    declare_parameter<double>("wheel_no_effect_min_bus_voltage_v", 18.0));
  wheel_no_effect_command_warmup_cycles_ = static_cast<std::uint32_t>(
    declare_parameter<int>("wheel_no_effect_command_warmup_cycles", 12));
  wheel_no_effect_trigger_cycles_ = static_cast<std::uint32_t>(
    declare_parameter<int>("wheel_no_effect_trigger_cycles", 30));
  wheel_no_effect_attempt_limit_ = static_cast<std::uint32_t>(
    declare_parameter<int>("wheel_no_effect_attempt_limit", 2));
  wheel_no_effect_cooldown_ms_ = static_cast<std::uint32_t>(
    declare_parameter<int>("wheel_no_effect_cooldown_ms", 1200));
  wheel_recovery_verify_timeout_ms_ = static_cast<std::uint32_t>(
    declare_parameter<int>("wheel_recovery_verify_timeout_ms", 180));
  wheel_no_effect_diag_freshness_ms_ = static_cast<std::uint32_t>(
    declare_parameter<int>("wheel_no_effect_diag_freshness_ms", 350));
  wheel_no_effect_diag_request_period_ms_ = static_cast<std::uint32_t>(
    declare_parameter<int>("wheel_no_effect_diag_request_period_ms", 80));
  leg_no_effect_position_error_threshold_ = static_cast<float>(
    declare_parameter<double>("leg_no_effect_position_error_threshold", 0.18));
  leg_no_effect_velocity_epsilon_ = static_cast<float>(
    declare_parameter<double>("leg_no_effect_velocity_epsilon", 0.12));
  leg_no_effect_max_estimated_current_arms_ = static_cast<float>(
    declare_parameter<double>("leg_no_effect_max_estimated_current_arms", 4.0));
  leg_no_effect_max_abs_torque_nm_ = static_cast<float>(
    declare_parameter<double>("leg_no_effect_max_abs_torque_nm", 5.0));
  leg_no_effect_max_temperature_c_ = static_cast<float>(
    declare_parameter<double>("leg_no_effect_max_temperature_c", 100.0));
  leg_no_effect_min_bus_voltage_v_ = static_cast<float>(
    declare_parameter<double>("leg_no_effect_min_bus_voltage_v", 18.0));
  leg_no_effect_command_warmup_cycles_ = static_cast<std::uint32_t>(
    declare_parameter<int>("leg_no_effect_command_warmup_cycles", 40));
  leg_no_effect_trigger_cycles_ = static_cast<std::uint32_t>(
    declare_parameter<int>("leg_no_effect_trigger_cycles", 25));
  leg_no_effect_attempt_limit_ = static_cast<std::uint32_t>(
    declare_parameter<int>("leg_no_effect_attempt_limit", 2));
  leg_no_effect_cooldown_ms_ = static_cast<std::uint32_t>(
    declare_parameter<int>("leg_no_effect_cooldown_ms", 1200));
  leg_recovery_verify_timeout_ms_ = static_cast<std::uint32_t>(
    declare_parameter<int>("leg_recovery_verify_timeout_ms", 220));

  RCLCPP_INFO(get_logger(), "Initializing hardware bridge node (Dry run: %s)", dry_run_ ? "true" : "false");
  RCLCPP_INFO(get_logger(), "Event log file: %s", event_logger_.componentLogPath().c_str());
  RCLCPP_INFO(get_logger(), "Run log directory: %s", run_log_dir_.c_str());
  logEvent("INFO", "node_start", dry_run_ ? "Hardware bridge node started in dry-run mode." : "Hardware bridge node started.");
  if (safety_enabled_) {
    RCLCPP_INFO(get_logger(), "Safety monitoring is ENABLED (tilt threshold: %f, ang_vel threshold: %f)", max_tilt_z, max_ang_vel);
  } else {
    RCLCPP_WARN(get_logger(), "Safety monitoring is DISABLED!");
  }

  // 2. Set up logical motors mapping matching contract
  // Mapping index in array matches joint ordering in kJointLabels
  for (std::size_t i = 0; i < 16; ++i) {
    motors_[i].direction = sim2real_common::DeploymentContract::kDirectionMap[i];
    motors_[i].offset = sim2real_common::DeploymentContract::kZeroOffsetMap[i];
    motors_[i].bus = sim2real_common::DeploymentContract::kCanBusMap[i];
    motors_[i].id = sim2real_common::DeploymentContract::kCanIdMap[i];
  }

  // 3. Initialize filters & safety monitors
  lpf_legs_ = std::make_unique<sim2real_common::LowPassFilter>(5.0, 0.005, 12);
  lpf_wheels_ = std::make_unique<sim2real_common::LowPassFilter>(15.0, 0.005, 4);
  mahony_filter_ = std::make_unique<sim2real_common::MahonyFilter>(2.0f, 0.0f);

  safety_monitor_ = std::make_unique<sim2real_common::SafetyMonitor>(
    static_cast<float>(max_target_offset),
    static_cast<float>(max_ang_vel),
    static_cast<float>(max_tilt_z),
    clip_to_brake,
    static_cast<float>(hard_target_offset)
  );
  model_switch_safety_monitor_ = std::make_unique<sim2real_common::SafetyMonitor>(
    static_cast<float>(model_switch_max_target_offset),
    static_cast<float>(max_ang_vel),
    static_cast<float>(max_tilt_z),
    clip_to_brake,
    static_cast<float>(hard_target_offset)
  );

  runtime_guard_ = std::make_unique<sim2real_common::RuntimeGuard>(
    static_cast<float>(max_ang_vel + 2.0), // slightly higher limit for runtime guard stop
    static_cast<float>(max_tilt_z),
    static_cast<float>(imu_age_warn_ms),
    static_cast<float>(imu_age_stop_ms)
  );

  // 4. Initialize CAN sockets if not in dry-run
  if (!dry_run_) {
    if (!initCan(can0_name_, can0_fd_) || !initCan(can1_name_, can1_fd_)) {
      RCLCPP_ERROR(get_logger(), "CAN initialization failed! Falling back to dry-run.");
      dry_run_ = true;
    }
  }

  // 5. Initialize motor target states
  latest_target_ = rough_default_dof_pos_;
  latest_raw_action_.fill(0.0f);

  // 6. Set up ROS publishers & subscriptions
  motor_callback_group_ = create_callback_group(rclcpp::CallbackGroupType::MutuallyExclusive);
  sensor_callback_group_ = create_callback_group(rclcpp::CallbackGroupType::MutuallyExclusive);
  control_callback_group_ = create_callback_group(rclcpp::CallbackGroupType::MutuallyExclusive);

  rclcpp::SubscriptionOptions sensor_sub_options;
  sensor_sub_options.callback_group = sensor_callback_group_;
  rclcpp::SubscriptionOptions control_sub_options;
  control_sub_options.callback_group = control_callback_group_;

  state_pub_ = create_publisher<sim2real_interfaces::msg::RuntimeState>("runtime/state", 10);
  target_sub_ = create_subscription<sim2real_interfaces::msg::RuntimeTarget>(
    "runtime/target", 10,
    std::bind(&HardwareBridgeNode::onTarget, this, std::placeholders::_1),
    control_sub_options);
  model_status_sub_ = create_subscription<std_msgs::msg::String>(
    "runtime/model_status", 10,
    std::bind(&HardwareBridgeNode::onModelStatus, this, std::placeholders::_1),
    control_sub_options);
  std::string imu_topic = declare_parameter<std::string>("imu_topic", "/odin1/imu");
  imu_sub_ = create_subscription<sensor_msgs::msg::Imu>(
    imu_topic, 10,
    std::bind(&HardwareBridgeNode::onImu, this, std::placeholders::_1),
    sensor_sub_options);
  estop_sub_ = create_subscription<std_msgs::msg::Bool>(
    "/safety/estop", 10,
    std::bind(&HardwareBridgeNode::onEstop, this, std::placeholders::_1),
    control_sub_options);

  // Odom subscription
  std::string odom_topic = declare_parameter<std::string>("odom_topic", "/odom");
  odom_sub_ = create_subscription<nav_msgs::msg::Odometry>(
    odom_topic, 10,
    std::bind(&HardwareBridgeNode::onOdom, this, std::placeholders::_1),
    sensor_sub_options);

  // 7. Enable motors on total startup
  if (!dry_run_) {
    RCLCPP_INFO(get_logger(), "Enabling RobStride motors...");
    for (std::size_t i = 0; i < 16; ++i) {
      initializeMotor(i, "startup_init");
    }
  }

  // 8. Timers at 200Hz (5ms)
  read_timer_ = create_wall_timer(
    5ms, std::bind(&HardwareBridgeNode::onReadLoop, this), motor_callback_group_);
  write_timer_ = create_wall_timer(
    5ms, std::bind(&HardwareBridgeNode::onWriteLoop, this), motor_callback_group_);
}

HardwareBridgeNode::~HardwareBridgeNode()
{
  if (!dry_run_) {
    RCLCPP_INFO(get_logger(), "Disabling RobStride motors on shutdown...");
    for (std::size_t i = 0; i < 16; ++i) {
      int fd = (motors_[i].bus == 1) ? can0_fd_ : can1_fd_;
      logMotorPowerEvent(i, "disabled", "node shutdown requested motor disable");
      disableMotor(fd, motors_[i].id);
    }
    if (can0_fd_ >= 0) {
      if (::close(can0_fd_) < 0) {
        RCLCPP_WARN(get_logger(), "Failed to close can0 socket: %s", strerror(errno));
      }
    }
    if (can1_fd_ >= 0) {
      if (::close(can1_fd_) < 0) {
        RCLCPP_WARN(get_logger(), "Failed to close can1 socket: %s", strerror(errno));
      }
    }
  }
  logEvent("INFO", "node_stop", "Hardware bridge node stopped.");
  finalizeRunSummary();
}

void HardwareBridgeNode::logEvent(
  const std::string & level,
  const std::string & event,
  const std::string & message)
{
  event_logger_.log(level, "sim2real_hw_node", event, message);
}

const char * HardwareBridgeNode::jointName(std::size_t index) const
{
  return sim2real_common::kJointLabels[index];
}

std::string HardwareBridgeNode::motorTag(std::size_t index) const
{
  std::ostringstream oss;
  oss << jointName(index)
      << "(index=" << index
      << ",bus=" << motors_[index].bus
      << ",id=" << motors_[index].id
      << ")";
  return oss.str();
}

float HardwareBridgeNode::estimateCurrentArms(float torque_nm) const
{
  constexpr float kTorqueConstantNmPerArms = 1.22f;
  return std::abs(torque_nm) / kTorqueConstantNmPerArms;
}

std::string HardwareBridgeNode::decodeFaultCode(std::uint16_t fault_code) const
{
  if (fault_code == 0) {
    return "none";
  }

  std::vector<std::string> reasons;
  if (fault_code & (1u << 14)) reasons.emplace_back("stall_or_overload");
  if (fault_code & (1u << 7)) reasons.emplace_back("encoder_not_calibrated");
  if (fault_code & (1u << 3)) reasons.emplace_back("bus_overvoltage");
  if (fault_code & (1u << 2)) reasons.emplace_back("bus_undervoltage");
  if (fault_code & (1u << 1)) reasons.emplace_back("driver_chip_fault");
  if (fault_code & (1u << 0)) reasons.emplace_back("overtemperature");
  if (reasons.empty()) reasons.emplace_back("unknown_fault_bits");

  std::ostringstream oss;
  for (std::size_t i = 0; i < reasons.size(); ++i) {
    if (i > 0) {
      oss << '|';
    }
    oss << reasons[i];
  }
  return oss.str();
}

std::string HardwareBridgeNode::decodeFaultDetailRegister(std::uint16_t register_value, int register_index) const
{
  if (register_value == 0) {
    return "none";
  }

  std::ostringstream oss;
  if (register_index == 1) {
    oss << "driver_fault_reg1=0x" << std::hex << register_value
        << " (possible: mos_overcurrent_or_uvlo)";
  } else {
    oss << "driver_fault_reg2=0x" << std::hex << register_value
        << " (possible: gate_driver_short_or_half_bridge_damage)";
  }
  return oss.str();
}

std::string HardwareBridgeNode::buildMotorFaultSummary(std::size_t index) const
{
  const auto & state = motor_states_[index];
  std::ostringstream oss;
  oss << "motor=" << motorTag(index)
      << ", fault_code=0x" << std::hex << state.fault_code << std::dec
      << ", decoded_fault=" << decodeFaultCode(state.fault_code)
      << ", temperature_c=" << state.temperature
      << ", estimated_current_arms=" << state.estimated_current_arms;
  if (state.has_bus_voltage) {
    oss << ", bus_voltage_v=" << state.bus_voltage;
  }
  if (state.fault_detail_1 != 0) {
    oss << ", " << decodeFaultDetailRegister(state.fault_detail_1, 1);
  }
  if (state.fault_detail_2 != 0) {
    oss << ", " << decodeFaultDetailRegister(state.fault_detail_2, 2);
  }
  return oss.str();
}

std::string HardwareBridgeNode::formatProtectionReason(
  const std::string & trigger,
  const std::string & reason) const
{
  std::ostringstream oss;
  oss << "trigger=" << trigger
      << ", protection_action=safety_brake, reason=" << reason;
  return oss.str();
}

void HardwareBridgeNode::logProtectionEvent(
  const std::string & trigger,
  const std::string & reason,
  const std::string & action)
{
  protection_trigger_count_++;
  std::ostringstream oss;
  oss << "trigger=" << trigger
      << ", protection_action=" << action
      << ", reason=" << reason;
  std::size_t suspect_index = motors_.size();
  float suspect_score = -1.0f;
  for (std::size_t i = 0; i < motors_.size(); ++i) {
    float score = 0.0f;
    if (motor_states_[i].fault_code != 0 || motor_states_[i].fault_detail_1 != 0 || motor_states_[i].fault_detail_2 != 0) {
      score += 100.0f;
    }
    score += motor_states_[i].temperature;
    score += 2.0f * motor_states_[i].estimated_current_arms;
    score += std::min<float>(50.0f, static_cast<float>(motor_states_[i].stale_count));
    if (score > suspect_score) {
      suspect_score = score;
      suspect_index = i;
    }
  }
  if (suspect_index < motors_.size()) {
    oss << ", suspect_motor={" << buildMotorFaultSummary(suspect_index) << "}";
  }
  logEvent("ERROR", "protection_triggered", oss.str());
}

void HardwareBridgeNode::logMotorPowerEvent(
  std::size_t index,
  const std::string & state,
  const std::string & reason)
{
  std::ostringstream oss;
  oss << "motor=" << motorTag(index)
      << ", state=" << state
      << ", reason=" << reason;
  logEvent(state == "recovered" ? "INFO" : "WARN", "motor_power_state", oss.str());
}

void HardwareBridgeNode::logMotorDiagnosticEvent(
  std::size_t index,
  const std::string & event,
  const std::string & reason,
  const char * level)
{
  std::ostringstream oss;
  oss << "motor=" << motorTag(index) << ", " << reason;
  logEvent(level, event, oss.str());
}

void HardwareBridgeNode::finalizeRunSummary()
{
  std::ostringstream oss;
  oss << "run_dir=" << run_log_dir_
      << ", protection_trigger_count=" << protection_trigger_count_
      << ", motor_drop_event_count=" << motor_drop_event_count_
      << ", motor_recover_event_count=" << motor_recover_event_count_
      << ", motor_fault_event_count=" << motor_fault_event_count_
      << ", holdover_events_total=" << holdover_events_total_
      << ", final_safety_triggered=" << (safety_triggered_ ? "true" : "false");
  if (!safety_reason_.empty()) {
    oss << ", final_safety_reason=" << safety_reason_;
  }
  event_logger_.logSummary("sim2real_hw_node", oss.str());
}
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
int main(int argc, char ** argv)
{
  rclcpp::init(argc, argv);
  auto node = std::make_shared<sim2real_hw::HardwareBridgeNode>();
  rclcpp::executors::MultiThreadedExecutor executor(rclcpp::ExecutorOptions(), 6);
  executor.add_node(node);
  executor.spin();
  rclcpp::shutdown();
  return 0;
}

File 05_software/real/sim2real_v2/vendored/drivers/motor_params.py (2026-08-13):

import numpy as np
import struct

class CommunicationType:
    """
    电机通信类型定义 (Bit28~24)
    参考说明书 4.1 章节
    
    通信 ID 结构 (29位扩展帧):
    | Bit 28-24 | Bit 23-8 | Bit 7-0 |
    | 通信类型   | 数据区2  | 目标地址 |
    """
    GET_DEVICE_ID       = 0   # 获取设备 ID 和 64 位 MCU 唯一标识符 (Type 0)
    OPERATION_CONTROL   = 1   # 运控模式电机控制指令 (MIT 模式) (Type 1)
    OPERATION_STATUS    = 2   # 电机反馈数据 (标准反馈帧) (Type 2)
    ENABLE              = 3   # 电机使能运行 (Type 3)
    DISABLE             = 4   # 电机停止运行 (可用于清除故障) (Type 4)
    SET_ZERO_POSITION   = 6   # 设置电机机械零位 (设置当前位置为零点) (Type 6)
    SET_CAN_ID          = 7   # 设置电机 CAN ID (立即生效，需保存) (Type 7)
    READ_PARAMETER      = 17  # 单个参数读取 (Type 17, 0x11)
    WRITE_PARAMETER     = 18  # 单个参数写入 (Type 18, 0x12, 掉电丢失)
    FAULT_REPORT        = 21  # 故障反馈帧 (Type 21, 0x15)
    SAVE_PARAMETERS     = 22  # 电机数据保存帧 (保存所有参数到 Flash) (Type 22)
    SET_BAUDRATE        = 23  # 电机波特率修改帧 (重新上电生效) (Type 23)
    ACTIVE_REPORT       = 24  # 电机主动上报设置帧 (开启/关闭主动上报) (Type 24)
    PROTOCOL_SWITCH     = 25  # 电机协议修改帧 (切换 Canopen/MIT/私有协议) (Type 25)
    READ_VERSION        = 26  # 版本号读取帧 (Type 26)

class RunMode:
    """
    电机运行模式 (参数索引 0x7005)
    参考说明书 4.3 章节
    """
    MIT                 = 0   # 运控模式 (默认): 适用于高动态响应控制
    POS_PP              = 1   # 位置模式 (PP): 梯形加减速位置控制
    SPEED               = 2   # 速度模式: 闭环速度控制
    CURRENT             = 3   # 电流模式: 闭环力矩(电流)控制
    POS_CSP             = 5   # 位置模式 (CSP): 循环同步位置模式 (适用于周期性指令)

class BaudRate:
    """
    电机波特率 (通信类型 23)
    参考说明书 4.1 通信类型 23
    注意: 修改后需重新上电生效
    """
    BAUD_1M             = 1   # 1 Mbps (默认)
    BAUD_500K           = 2   # 500 Kbps
    BAUD_250K           = 3   # 250 Kbps
    BAUD_125K           = 4   # 125 Kbps

class ActiveReportStatus:
    """
    电机主动上报状态 (通信类型 24)
    参考说明书 4.1 通信类型 24
    """
    DISABLE             = 0   # 关闭主动上报 (默认)
    ENABLE              = 1   # 开启主动上报 (默认间隔 10ms, 可通过 EP_SCAN_TIME 修改)

class ProtocolType:
    """
    电机协议类型 (通信类型 25)
    参考说明书 4.2.4 章节
    注意: 切换协议后需重新上电生效
    """
    PRIVATE             = 0   # 私有协议 (默认): 使用 29 位扩展帧
    CANOPEN             = 1   # CANopen 协议: 符合 CiA 402 标准
    MIT                 = 2   # MIT 协议 (标准帧): 使用 11 位标准帧

class ParamType:
    """
    参数数据类型定义
    
    - 私有协议 (Type 17/18) 参数表主要使用 UINT8/UINT16/UINT32/FLOAT
    - CANopen 对象字典会用到有符号类型 (INTEGER8/16/32)
    """
    UINT8               = 0   # 无符号 8 位整数
    UINT16              = 1   # 无符号 16 位整数
    UINT32              = 2   # 无符号 32 位整数
    FLOAT               = 3   # 32 位浮点数 (IEEE 754)
    INT8                = 4   # 有符号 8 位整数
    INT16               = 5   # 有符号 16 位整数
    INT32               = 6   # 有符号 32 位整数

class ErrorCode:
    """
    异常状态 fault 值位定义
    
    说明书位置:
    - 章节 6 (Mit) 的“异常状态应答帧”对 fault 值 bit 位做了明确描述
    - 私有协议 Type 21 故障反馈帧也会携带 fault/warning 值
    """
    OVER_TEMP           = 1 << 0  # bit0: 电机过温故障 (默认 >145°C)
    DRIVE_CHIP          = 1 << 1  # bit1: 驱动芯片故障 (DRV8353 等报告错误)
    UNDER_VOLTAGE       = 1 << 2  # bit2: 欠压故障 (电压 < 12V)
    OVER_VOLTAGE        = 1 << 3  # bit3: 过压故障 (电压 > 60V)
    CURRENT_B_OVER      = 1 << 4  # bit4: B 相电流采样过流
    CURRENT_C_OVER      = 1 << 5  # bit5: C 相电流采样过流
    ENCODER_NOT_CALIB   = 1 << 7  # bit7: 编码器未标定
    HARDWARE_ERR        = 1 << 8  # bit8: 硬件识别故障
    POS_INIT_ERR        = 1 << 9  # bit9: 位置初始化故障
    LOAD_BLOCK          = 1 << 14 # bit14: 堵转过载算法保护
    CURRENT_A_OVER      = 1 << 16 # bit16: A 相电流采样过流

class WarningCode:
    """
    预警状态 warning 值位定义 (Type 21 Byte 4-7)
    """
    OVER_TEMP_WARNING   = 1 << 0  # bit0: 电机过温预警 (默认 >135°C)

class DriveFault1:
    """
    驱动芯片故障码 1 (0x3024) - DRV8353 状态寄存器 1
    参考说明书 3.3.7 章节
    """
    VDS_LC              = 1 << 0  # VDS overcurrent on C low-side (C相下管VDS过流)
    VDS_HC              = 1 << 1  # VDS overcurrent on C high-side (C相上管VDS过流)
    VDS_LB              = 1 << 2  # VDS overcurrent on B low-side (B相下管VDS过流)
    VDS_HB              = 1 << 3  # VDS overcurrent on B high-side (B相上管VDS过流)
    VDS_LA              = 1 << 4  # VDS overcurrent on A low-side (A相下管VDS过流)
    VDS_HA              = 1 << 5  # VDS overcurrent on A high-side (A相上管VDS过流)
    OTSD                = 1 << 6  # Overtemperature shutdown (过温关断)
    UVLO                = 1 << 7  # Undervoltage lockout (欠压锁定)
    GDF                 = 1 << 8  # Gate drive fault (栅极驱动故障)
    VDS_OCP             = 1 << 9  # VDS monitor overcurrent (VDS 监控过流)
    FAULT               = 1 << 10 # Logic OR of FAULT status (故障状态逻辑或)
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

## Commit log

2026-08-13 更新02_mechanical README：添加致谢与修改说明
2026-08-13 更新02_mechanical README：删除版本提示，新增装配体版本说明
2026-08-13 添加8DOF串联足机器人CAD源文件
    [21 15 4的轴承 2.0.SLDPRT, 5m同步带1 2.0.SLDPRT, DOG总装.SLDASM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]
2026-08-13 Sync main with source v0.3.1
    [21 15 4的轴承 2.0.SLDPRT, 5m同步带1 2.0.SLDPRT, DOG总装.SLDASM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]
2026-08-13 更新readme.md以及相关信息
2026-08-13 更新readme.md
2026-08-13 更新成员 GitHub 链接
2026-08-13 修正成员 GitHub 链接
2026-08-13 修正部分README表述
2026-08-14 Add SolidWorks part files
    [新身子板6.圆角SLDPRT.SLDPRT, 电机连接3.3加宽SLDPRT.SLDPRT, 电机连接4.11 SLDPRT.SLDPRT]
2026-08-14 Update acknowledgments in README.md
    Corrected a typo in the list of supporting universities and added '晋中信息信息学院' to the acknowledgment section.
2026-08-16 整理第一份新版 MJCF 与 mjlab 训练框架
    [sim2sim_temp.xml, wheelleg.xml]
2026-08-19 整理比赛最终训练架构
2026-08-19 Update current status section in README
2026-08-23 更新 README 文档
2026-08-25 整理 backup-v0.9.0 ROS2 最终部署
    [calib.yaml]
2026-08-25 更新 README 版本说明
2026-09-02 整理 ROS 2/C++ Sim2Real 初版
    [base_link.STL, fl_hip_abduction_Link.STL, fl_hip_pitch_Link.STL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]
2026-09-02 更新完赛效果演示视频
2026-09-02 更新实机展示媒体
2026-09-02 ROS 2/C++ 初版与导航原型
2026-09-15 同步 v1.1.0 代码与 README
    [calib.yaml]
2026-09-16 最终整理完整开源资料
    [轮足BOM表（初版）.xlsx]
